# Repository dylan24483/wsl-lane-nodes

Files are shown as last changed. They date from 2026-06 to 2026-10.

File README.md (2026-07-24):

# wsl-lane-nodes

Phase 8 of the Westside Lanes Conqueror replacement project. Each Pi 4 controls one lane pair, replacing the QubicaAMF stack (BCU II + QBK-SIx + T-VISION + VDB-99) with direct GPIO control of the AMF 8270 cabinet I/O. Pi nodes connect to WSL-SRV via WebSocket and feed events into the existing wsl_scoring_engine.

## Status: bench rig fully validated (2026-05-06)

**What runs end-to-end on the bench:**

- [x] Pi GPIO + WebSocket + scoring engine + browser display (night-1 prototype, 2026-05-01)
- [x] AEDIKO 8-channel relay HAT + AL-ZARD DST-1R8P-P opto-input bench rig validated
- [x] Per-pair (lanes 21 + 22): 4 inputs (foul × 2 + 2nd-ball × 2) + 4 outputs (cycle × 2 + power × 2)
- [x] Both control modes proven: pulsed cycle + latched power on/off
- [x] Production safety: SIGTERM handler + `try/finally` on `pulse()` + systemd `ExecStopPost=` cleanup (3 of 4 K-mitigations; hardware watchdog is the 4th)
- [x] Foul-event vs ball-detect semantic separation (BALL_EVENT carries pin_mask + foul flag)
- [x] OpenCV pin-detect pipeline skeleton (synthetic-image self-test passes)
- [x] SQLite state persistence — server restarts don't wipe in-progress games
- [x] WebSocket protocol versioning
- [x] Server portable to WSL-SRV (Windows) or stays on Pi for dev

**Active gates before Phase 8a cutover:**

- [ ] Lane 22 characterization visit — see [docs/lane_visit_checklist.md](docs/lane_visit_checklist.md)
- [ ] T-Camera + USB capture dongle on bench — calibrate `pin_detect.PIN_SPOTS` against real frames
- [ ] Hardware watchdog perfboard build — see [docs/hardware_watchdog_design.md](docs/hardware_watchdog_design.md)

## Layout

| Path | What |
|---|---|
| `lane_node/lane_node.py` | Pi-side daemon — multi-lane GPIO, WebSocket client, signal handlers |
| `lane_node/relay_cleanup.py` | Standalone GPIO cleanup script run by systemd `ExecStopPost=` |
| `lane_node/pin_detect.py` | OpenCV pipeline skeleton + synthetic-image self-test |
| `server/lane_node_server.py` | Server — WebSocket + HTTP display + desk simulator UI + `/api/health` |
| `server/state_store.py` | SQLite persistence helpers + CLI for state inspection |
| `systemd/lane-node.service` | systemd unit for production deployment |
| `prototypes/` | Scaffolding scripts that proved individual pieces during night-1 |
| `wsl_scoring_engine.py` | Copied from wsl-systems — handles bowling logic |
| `docs/lane_visit_checklist.md` | On-site procedure for the lane characterization visit |
| `docs/hardware_watchdog_design.md` | CD4538B + MOSFET watchdog circuit spec for the 4th K-pillar |
| `docs/deploy_server_to_wsl_srv.md` | Step-by-step for moving the server to WSL-SRV |

## Run on the Pi

Two SSH sessions, server in one + lane node in the other:

```bash
# Session 1 — server
cd ~/wsl-lane-nodes && source .venv/bin/activate
WSL_MACHINE_LANES=21,22 \
WSL_SCORING_NODE_TOPOLOGY=pi-lane21-22=21,22 \
WSL_ALLOW_UNAUTHENTICATED_BENCH=1 \
python3 server/lane_node_server.py

# Session 2 — lane node daemon
cd ~/wsl-lane-nodes && source .venv/bin/activate
WSL_LANE_NODE_ID=pi-lane21-22 WSL_DIAG_SOURCE_ID=pi-lane21-22 \
WSL_LANES=21,22 WSL_ALLOW_UNAUTHENTICATED_BENCH=1 \
python3 lane_node/lane_node.py
```

Browser at `http://lane-node-dev.local:8766/` — Open Lane / Close Lane / Reset Pins / Power On/Off / Trigger Ball buttons per lane.

## Run server on WSL-SRV instead of Pi

```bash
# On WSL-SRV (Windows): see docs/deploy_server_to_wsl_srv.md
# On the Pi:
WSL_LANE_SERVER_URL=ws://192.168.4.103:8765 \
WSL_LANE_NODE_ID=pi-lane21-22 WSL_DIAG_SOURCE_ID=pi-lane21-22 \
WSL_LANES=21,22 LANE_NODE_TOKEN=<shared-secret> \
WSL_SCORING_NODE_TOKEN=<unique-pi-secret> python3 lane_node/lane_node.py
# (192.168.4.103 = WSL-SRV since the 2026-06-03 eero re-IP; confirm the live IP —
#  the DHCP reservation is still TODO. The old 192.168.86.36 is dead.)
```

## Health check

```bash
curl http://lane-node-dev.local:8766/api/health
```

Returns server uptime, connected node summary, per-lane state, pending foul flags, state DB path.

## State inspection

```bash
python3 server/state_store.py            # print current saved state
python3 server/state_store.py clear      # wipe saved state
```

## Test pin detection on synthetic frames

```bash
python3 lane_node/pin_detect.py
```

Runs 7 synthetic-image test cases (strike, gutter, head pin only down, 7-10 split, etc.) and reports pass/fail. Validates the pipeline shape; real-camera calibration of `PIN_SPOTS` is a separate step.

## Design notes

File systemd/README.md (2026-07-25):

# Lane-node systemd units — topology & health hand-off

Two units, **mutually exclusive** (`lane-node-controller.service`
`Conflicts=lane-node.service`), one Pi:

| Unit | Track | Role | Health class it emits |
|---|---|---|---|
| `lane-node.service` | A | camera scoring (`lane_node.py`) | `camera_health`, `camera_ref_drift`, `gs_camera_disagree` |
| `lane-node-controller.service` | B | 82-70 controller replacement (`controller_daemon.py`) | `service_restart*`, `pi_thermal`, `pi_disk_low`, `pi_fs_readonly`, `pi_undervoltage`, `uart_drops`, FSM/firmware faults, `fw_identity*` |

Both require the shared per-Pi env (`EnvironmentFile=/etc/wsl-lane-node.env`,
see `wsl-lane-node.env.example`): `WSL_DIAG_SERVER_URL`, `LANE_NODE_TOKEN`,
the distinct `WSL_SCORING_NODE_TOKEN`, `WSL_LANE_NODE_ID`, matching
`WSL_DIAG_SOURCE_ID`, `WSL_BOARD_REVS`, and the exact paired `WSL_LANES`.

## Per-board AUX diagnostics

A two-board service must provision each physical board independently with
`WSL_DIAG_AUX_ROLES_L<lane>`; for example:

```text
WSL_DIAG_AUX_ROLES_L21=aux2=exit_beam,aux3=dist_index,aux10=sensor_24v_ok
WSL_DIAG_AUX_ROLES_L22=aux3=dist_index,aux10=sensor_24v_ok
```

The exit photoeye is one pair-shared sensor, so exactly one board may map
`exit_beam`. The daemon validates this before opening hardware and again when
wiring the pair tracker. `sensor_24v_ok` and `dist_index` remain board-local;
if one supply spans the pair, each board needs its own isolated monitor-contact
pole. Once either board has an explicit map, omission of the mate is a startup
error; a present-but-empty lane variable explicitly leaves that board unmapped.
The legacy unscoped `WSL_DIAG_AUX_ROLES` variable is accepted only when
`WSL_LANES` selects one board; a multi-board service refuses it instead of
silently cloning roles onto an unwired mate.

## R3-2 — controller heartbeat / lease renewal (why a quiet controller stays HEALTHY)

The :8766 server derives each machine lane's board state from a **lease**
(`machine_leases.last_seen`): fresh → HEALTHY/FAULT, stale (> `WSL_MACHINE_LEASE_S`,
default 90 s) → OFFLINE, never-heard → UNKNOWN. Track A refreshes the lease
through the scoring **WS heartbeat**. **Track B sends no scoring WS**, so a
healthy-but-quiet controller used to expire OFFLINE at 90 s (Codex R3-2
wrong-topology bug).

`controller_daemon`'s `PlatformHealth` thread now POSTs
`/api/machine/heartbeat` per board every `WSL_MACHINE_HEARTBEAT_S` (default
20 s — well under the 90 s window), carrying board revision + firmware
build/config hashes + the machine-contract digest + outbox health. The server
touches the lease identically to the WS/ingest path. Requires
`WSL_DIAG_SERVER_URL` set; behind `LANE_NODE_TOKEN` when armed.

## R3-11 — shared health-drop hand-off (why both health classes reach the desk)

Because the two units are mutually exclusive, whichever one is running would
otherwise be the only health class the desk ever sees. The **shared drop file**
`${WSL_DIAG_DIR:-./diag_logs}/health_drop.json` (`lane_node/health_drop.py`,
atomic tmp+`os.replace`) bridges the hand-off:

- Each service writes its **own** last-known health block to the drop file.
- The service that is running (it has transport) also **reads the other
  service's** drop and ships it to the store as an info event flagged with its
  age (`age_s`) — a last-known snapshot, not live.

So on a Track-B (controller) box the desk still sees the camera service's
last-known health, and vice-versa. A read-only filesystem (R3-10) makes the
drop write a counted no-op; the reader simply finds no fresh foreign drop, and
the controller's own platform health still reaches the desk via the network
heartbeat.

## R3-5 — firmware identity ARM gate (controller only)

A rev-D board reports a firmware **identity** line (revision straps, build +
config.h hashes, FI-1 posture). A reboot **invalidates** the cached identity;
the daemon re-requests it. Missing identity (after retries, on a strapped
board) or a mismatch (wrong pcb revision / an FI-1 bench image) **inhibits
ARM**. Bench escape: `WSL_ALLOW_IDENTITY_MISMATCH=1` (loudly logged). rev-B/C
boards and pre-v1.2.2 firmware never report identity and are unaffected.

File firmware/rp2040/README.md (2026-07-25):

# WSL Phase 8b — RP2040 lane-controller firmware

**v1.2.3 — controlled Rev-D-only release artifacts built, but NOT FLASHED; bench/first-article gates remain mandatory before any live-machine use. Full version history and exact release provenance: `CHANGELOG.md` and `release/firmware_manifest.json`.**
*(v1.2.2, 2026-07-21 — Codex round-2 R2-1/R2-13/R2-6 — **NOT flashed**: pad-level OEOVER output lock + `STATUS.OETOPAD` readback on EVERY input-contract pin (the SIO-only check had an override bypass), epoch-aware rail-predicate cause classifier (pre-reboot ring entries are history-only, never fresh diagnosis), the bench-only FI-1 fault-injection build (compile-flag + BOOTSEL-jumper + arm-command gated; separate artifact name; zero code in release), and the identity line: REV_ID strap read (GP20/GP21), Pico unique id, deterministic controlled source/toolchain build ID + config hash, hb `rid` field. All additive; `rp2040_link.py` consumes id/rid.)*
*(v1.2.0, 2026-07-21 — rev-D remediation R3, closes Codex C2 — **NOT yet flashed**: GP16-19 rev-D diagnostic taps get an ENFORCED input-only invariant (choke-point init + register readback each heartbeat + a host direction-invariant test that fails the build if any code path drives them), the INVERTED tap decode (2N7002 stage: raw 0 = observed HIGH, one `tap_read()` inversion point), a 1 ms-timestamped rail-predicate edge ring in noinit RAM that survives reboot (magic + epoch; `TAPDUMP`/`TAPCLR`), and VCC_5V ADC sampling on GP26 folded into the heartbeat. The four taps observe watchdog/ARM/RP2040 predicates only; they do **not** directly observe `RELAY_ENABLE_RAIL`/TP16 and cannot by themselves detect Q14/J14/rail stuck-on or stuck-open behavior. **All additive**: v1.1 line formats + command grammar unchanged, all v1.1 enforcement flags still default OFF, safety-critical paths byte-for-byte logic-identical. Rev-D board only — on rev-B/rev-C these pins are unconnected (an IRQ storm guard keeps floating-pin noise harmless). Binding contract: `docs/phase8_revD_remediation_spec_2026-07-21.md` §R3.)*
*(v1.1.1, 2026-07-06 review fixes (findings 37/56/58): boot `v11` enforcement-posture field; cam-stop grace arms on FIRST trip only; sliding chatter window. v1.1.0, 2026-06-10: cam-stop OVERRUN / SC-TB echo / motion-without-RUN, all default OFF. v0.2.0, 2026-06-10: audit hardening. See CHANGELOG.md.)*

> ⛔ **BENCH-CONFIRM BEFORE ENABLING the v1.1 flags.** `config.h` ships every v1.1 enforcement flag OFF and every per-cam trip edge as `'?'` (UNCONFIRMED). Confirm the per-cam edge→angle polarity on the spare cabinet (`docs/phase8_trackB_controller_cutover_runbook.md` §3.2) FIRST, then set `CAM_*_TRIP` + flip the matching `*_ENABLED` cam-by-cam and generate a new controlled release. Enabling with wrong polarity nuisance-trips the rail (safe direction) or fails to add the intended secondary diagnostic. **Candidate C is decided:** J_SAFE1-2 uses the documented keyed/labeled engineered jumper, while the OEM SC/TB ladder remains the primary hardware collision interlock and must pass the per-lane G3 S/T coil-drop proof. The firmware SC/TB echo remains default-off, unvalidated, and secondary. Never enable it blind or substitute it for the OEM-ladder proof.

One RP2040 (a stock Raspberry Pi Pico module) sits on each Rev-D controller board and is the **fast + safety half** of the lane controller. The Raspberry Pi runs the cycle FSM (`lane_node/cycle_control_8270.py`) and commands relays over I²C/MCP23017; this firmware owns the latency-critical inputs and the hardware rail-permission line. The controlled v1.2.3 bundle supports exactly `["revD"]`; do not flash it on Rev-B or Rev-C hardware.

> ⚠️ **Safety co-processor.** It drives `RP2040_OK` (GP2), a non-bypassable condition in the relay-enable-rail AND chain (spec §4.1). It is **never the only safety device** — the TB/SC collision interlock is the OEM parallel-safe-contact ladder in the S/T coil circuits (Candidate C), while the installed Stop/master-breaker path, NE555 watchdog (which watches the *Pi*), and regenerative motor braking remain hardware-independent of this firmware. Pilot lanes 21/22 have no C.I.S. device or wiring; another pit-entry interlock remains unresolved, and J14.3–4 must stay OPEN/no-arm until the approved isolated Stop/control-power interface and demand proof exist. Read the safety section before editing.

## What it does (v1)

1. **Reads 8 fast inputs** (6 cams + 2 DIELL ball beams), debounces, and **pushes edge events to the Pi over uart0** — the FSM consumes events, it does not poll, so cam timing isn't subject to Pi scheduling latency.
2. **Drives `RP2040_OK` (GP2)** = rail permission. **HIGH only when healthy; LOW on boot, fault, or hang.** Fail-safe by construction (see below).
3. **UART-independent safety backstops:**
   - **Firmware health** — the RP2040 hardware watchdog: if the main loop hangs, the chip resets → GP2 goes Hi-Z → the board's external 100k base-pulldown holds the rail **dead**.
   - **Motion max-run ("cam timeout", spec §4.2)** — if the Pi marks a guarded motor `RUN` and never `STOP`s it within `MAX_MOTION_MS` (8 s, matches the FSM), the firmware **latches a fault and drops RP_OK**.
4. **Heartbeats to the Pi** so a dead/`!ok` RP2040 is detected (the Pi then drops its ARM GPIO → rail drops).

### v1.1 SAFETY supervision (implemented, default OFF — arm per-cam after the §3.2 capture)

These are the cutover **G3 cam-stop rail-drop** backstops. The *code* is present + host-tested; the *enforcement* is gated OFF in `config.h` until the per-cam edge→angle polarity is bench-confirmed (`docs/phase8_trackB_controller_cutover_runbook.md` §3.2). Each only ever `latch_fault()`s (fail-safe: RP_OK → LOW).

1. **Cam-stop OVERRUN** — a stop cam's TRIP edge fires while its guarded motor is marked RUNNING and the Pi fails to `STOP` it within the per-cam grace window → latch `cam_overrun`. Per-cam: `CAM_SA_STOP_ENABLED`/`CAM_SA_TRIP`/`CAM_SA_GRACE_MS` (SA→sweep S), `CAM_TA1_*` (TA1→table T). **The Pi-independent, per-edge stop the post-cutover machine relies on** (runbook §0: cam-stops are SOLELY the RP2040's job once the Omniboard is unplugged).
2. **SC/TB collision-interlock echo** — both firmware inputs asserted at once while a motion motor runs → latch `interlock_collision`. `INTERLOCK_ECHO_ENABLED`. This default-off path is an unvalidated secondary diagnostic. The **primary** guard is Candidate C’s OEM ladder, proven per lane by forcing both levers BACK while the board commands S and T and verifying both coils remain dead.
3. **Motion-without-RUN** — a stop-cam TRIP edge while NO motion motor is marked RUNNING = the machine turning uncommanded (Pi wedged / external start / welded relay) → latch `motion_no_run`. `MOTION_NO_RUN_ENABLED`. The one check that works even if the Pi is fully wedged.

## Authoritative pin map

Source of truth: `scripts/generate_kicad_netlist_revD.py` → `block_rp2040()` and `kicad/wsl-phase8b-revD.net`. Re-verify against both if the board changes. **Do not** use the older `docs/phase8_channel_allocation.md` §2 GPIO column — it predates the live board (it had the fast inputs on GP0–GP7; Rev-D uses GP6–GP13).

| GPIO | Pico pin | Signal | Dir | Net | Notes |
|---|---|---|---|---|---|
| GP0 | 1 | UART0 TX → Pi RX | out | `PI_UART_RX` | protocol transport |
| GP1 | 2 | UART0 RX ← Pi TX | in | `PI_UART_TX` | protocol transport |
| GP2 | 4 | `RP2040_OK` | out | `RP2040_OK` | HIGH=permit, LOW=drop rail; fail-safe-low |
| GP6 | 9 | SA (sweep cam) | in | `FAST_SA` | active-low opto; 270 run-through / 360 zero |
| GP7 | 10 | SB (sweep cam) | in | `FAST_SB` | 66 guard / 186 table-spot init |
| GP8 | 11 | SC (sweep interlock cam) | in | `FAST_SC` | sweep-under-table 86–243 |
| GP9 | 12 | TA1 (table cam) | in | `FAST_TA1` | 355 zero / 185 delay-reset |
| GP10 | 14 | TA2 (table cam) | in | `FAST_TA2` | 260 run-through / pin-latch / ball-strike decision |
| GP11 | 15 | TB (table interlock cam) | in | `FAST_TB` | table-sweep interference 105–255 |
| GP12 | 16 | DIELL-L (ball) | in | `FAST_DIELL_L` | active-low opto; cushion SS trigger |
| GP13 | 17 | DIELL-R (ball) | in | `FAST_DIELL_R` | active-low opto |
| GP16 | 21 | tap: NE555 out (v1.2, **rev-D only**) | in (ENFORCED) | `TAP_NE555_OUT` | 2N7002 stage **INVERTS**: raw 0 = observed HIGH |
| GP17 | 22 | tap: watchdog kick (v1.2, rev-D) | in (ENFORCED) | `TAP_WDOG_KICK` | inverted |
| GP18 | 24 | tap: ARM permit (v1.2, rev-D) | in (ENFORCED) | `TAP_ARM_PERMIT` | inverted |
| GP19 | 25 | tap: RP2040_OK echo (v1.2, rev-D) | in (ENFORCED) | `TAP_RP2040_OK` | inverted; cross-checked vs our own GP2 |
| GP20 | 26 | REV_ID0 strap (v1.2.2, rev-D) | in (ENFORCED) | `REV_ID0` | 10k→3V3 on rev-D; read once at boot, pull-phase floating detect |
| GP21 | 27 | REV_ID1 strap (v1.2.2, rev-D) | in (ENFORCED) | `REV_ID1` | 10k→GND on rev-D; `REV_ID[1:0]=GP21<<1\|GP20`, rev-D=0b01 |
| GP26 | 31 | VCC_5V sense (v1.2, rev-D) | ADC0 | `ADC_VCC5_SENSE` | VCC_5V/2 via 10k/10k divider |

All fast inputs are **active-low** at the Pico (machine contact closed → GPIO LOW). Rev-D uses an on-board **47k** pull-up to 3V3; firmware explicitly disables the RP2040 internal pulls so their ~50–80k tolerance cannot sit in parallel and reduce the qualified optocoupler margin. A missing external pull-up is a board fault, not something firmware masks. The v1.2 diagnostic-tap pins are separate: they remain input-only with pulls OFF and use their own on-board **10k `Rtapd_*` drain pull-ups**. `tap_assert_input_only()` reads back the OE/function registers every heartbeat and latches a fail-safe `tap_dir` fault on drift; the host test fails the build if any code path ever drives them. **v1.2.2 (R2-1):** the invariant additionally forces + verifies the pad-level `CTRL.OEOVER=DISABLE` override and the live `STATUS.OETOPAD` bit on EVERY input-contract pin (taps, GP26, fast inputs, REV_ID) — the SIO-only readback had an OEOVER bypass; drift latches `pad_oe`.

## Build

Needs the [Raspberry Pi Pico SDK](https://github.com/raspberrypi/pico-sdk) + `arm-none-eabi-gcc` + CMake.

```powershell
# Controlled release path: host tests + clean release/FI-1 builds + manifest + verification
powershell -ExecutionPolicy Bypass -File .\release.ps1

# Re-verify an existing bundle before it is copied or flashed (no ARM toolchain needed)
powershell -ExecutionPolicy Bypass -File .\release.ps1 -VerifyOnly
```

`release.ps1` fixes `Release`, `PICO_BOARD=pico`, `DEBUG_USB=OFF`, refuses ambient
compiler/linker flags and a dirty Pico SDK, builds the release and FI-1 variants, and
writes `release/firmware_manifest.json`. The manifest binds both UF2 SHA-256 values to:

- the exact on-wire `id.build`, `id.cfg`, and `id.fi1`;
- full config/source-input SHA-256 values and the variant compile options;
- the clean Pico SDK commit, ARM compiler/CMake/Ninja versions, and CMake-cache hashes.
- an exact `supported_board_revisions: ["revD"]` deployment policy.
- an authoritative exact release tuple:
  `qualified_releases: ["revD|rel-0c746b5747143b8011b01d43|05d808411db4bb0d"]`.

The two exact manifest-named UF2s are committed as ordinary binary Git blobs:

- production `release/wsl_phase8b_rp2040.uf2` — SHA-256
  `d5570efd19c374d9ca4532b78ef36577ae93b88160b5c1775e92d1ef88c40aae`;
- bench-only `release/wsl_phase8b_rp2040_FI1.uf2` — SHA-256
  `7c1daabad0a102f55fa61d617d3b4f0722705770f109e2d941b5356b3378ae6c`.

`.gitattributes` pins every byte-hashed controlled source input to LF, so
`core.autocrlf` cannot change a clean-clone identity. The UF2 rules explicitly
disable text conversion, diff/merge drivers, and inherited LFS filters.

`id.build` is derived from the explicit firmware source/recipe allowlist,
image-affecting options, exact clean Pico SDK commit, and C compiler ID/version. A
different SDK/compiler therefore cannot announce the allowlisted identity. Application
repository Git status, timestamps, and unrelated dirty files are not inputs. `id.cfg` is
exactly the first 16 hex characters of `sha256(config.h)`. The manifest's
`qualified_releases` tuple is the authoritative ARM policy and is emitted as
`WSL_RP2040_QUALIFIED_RELEASES`; `supported_board_revisions` is emitted as
`WSL_RP2040_SUPPORTED_BOARD_REVISIONS`. Both must be provisioned. The independent
build/config lists remain provenance records only; they must never authorize their
Cartesian product. The FI-1 identity is deliberately excluded from every production policy.

`build.ps1` and direct CMake remain useful for developer/debug builds, but their output is
not a release artifact until the two-image manifest path above completes. **v1.2.3
re-verified 2026-07-23:** both images built successfully and their embedded identities and
hashes passed the independent manifest verifier. This is build evidence only, not flash or
bench evidence.

## Host logic test (no hardware)

The pure logic (TX ring, debounce/edges, ball lockout, UART protocol, the RP_OK safety supervisor) has a host unit test that mocks the Pico SDK — build + run it with any host C compiler:

```bash
# from firmware/rp2040/  (gcc or a MinGW clang; plain clang on Windows needs the Windows SDK for libc headers)

# (a) default build — v1.1 enforcement flags OFF (what ships); also pins the off-by-default inertness
gcc -std=c11 -Wall -Wextra -Werror -I test -I test/stubs test/test_main.c -o test/test_main.exe
./test/test_main.exe        # exit 0 = all checks pass

# (b) v1.1 SAFETY paths — SAME firmware, enforcement flags forced ON with test polarities ('f')
gcc -std=c11 -Wall -Wextra -Werror -I test -I test/stubs \
  -DCAM_SA_STOP_ENABLED=1 -DCAM_SA_TRIP="'f'" -DCAM_SA_GRACE_MS=150u \
  -DCAM_TA1_STOP_ENABLED=1 -DCAM_TA1_TRIP="'f'" -DCAM_TA1_GRACE_MS=150u \
  -DINTERLOCK_ECHO_ENABLED=1 -DMOTION_NO_RUN_ENABLED=1 \
  test/test_v11.c -o test/test_v11.exe
./test/test_v11.exe         # exit 0 = all checks pass

# (c) v1.2 tap/ring/ADC + THE C2 DIRECTION-INVARIANT GATE (rev-D remediation)
#     v1.2.2 adds: R2-1 OEOVER mutation gate, R2-13 epoch classifier, R2-6 REV_ID/identity
gcc -std=c11 -Wall -Wextra -Werror -I test -I test/stubs test/test_v12.c -o test/test_v12.exe
./test/test_v12.exe         # exit 0 = all checks pass

# (d) FI-1 bench build gates (v1.2.2 + v1.2.3): jumper refusal, arm-gate, drive/release,
#     banner identity, AND the v1.2.3 dead-man release paths (arm/drive timeout, UART loss, KA)
gcc -std=c11 -Wall -Wextra -Werror -I test -I test/stubs -DFI1_ENABLED=1 \
  test/test_fi1.c -o test/test_fi1.exe
./test/test_fi1.exe         # exit 0 = all checks pass
```

Last run: **64/64** (`test_main`) + **32/32** (`test_v11`) + **140/140** (`test_v12`) + **44/44** (`test_fi1`) checks passed (2026-07-23, gcc 16.1.0), all clean under `-Wall -Wextra -Werror` + the `printf`-format attribute (so the event format strings are compiler-verified too). The binaries share `test/mock_impl.h` (one mock-SDK implementation) so they can never drift. Sections F–I of `test_main` pin the v0.2.0 hardened semantics (UART fuzz/overrun-discard, duplicate-RUN, uint32 ms-wrap boot-settle latch, chatter guard + TX headroom, hb `in`/`run` masks); Section J pins that the v1.1 checks are **inert when the flags are OFF** (a default build = v0.2.0 enforcement); `test_v11.c` pins that each v1.1 fault path fires fail-safe when enabled (overrun latch + timely-STOP-cancels + per-motor disarm, SC∧TB echo, motion-without-RUN, and the non-trip-edge-is-inert guard). `test_v12.c` is the **C2 gate**: the mock SDK records every output-direction/write call per pin and the test FAILS if GP16-19/GP26 ever appear in one across init + operation + every fault path; it also requires all fast-input internal pulls OFF so Rev-D's qualified external 47k remains authoritative, tampers the mock OE register to prove `tap_assert_input_only()` trips, and covers the inverted decode, ring capture/wrap, reboot-persistence + epoch semantics, power-loss zeroing, TAPDUMP/TAPCLR + cause classification, ADC window, IRQ storm guard, and the RPOK cross-check (warn-only by default). **v1.2.3 (round-3)** adds `test_v12.c` section T (per-boot `bn` nonce: non-zero, differs across boots, id/hb-consistent, 0-reservation guard) and section U (the **R3-6 CLEAR pad-revalidation**: a violated input-only pad makes CLEAR a strict no-op — nak, fault stays latched, RP_OK stays low — while the fail-safe motor-stop half still runs), and `test_fi1.c` section E (the **FI-1 dead-man** release paths: arm timeout, drive timeout, UART loss, and the continuous `FI1 KA` token, plus a positive test that the 1 Hz bench KA cadence holds an injection with no false release).

> ⚠️ **Bench-only gates (the host test CANNOT prove these):** watchdog timing (the 250 ms WDT vs real loop latency — the mock watchdog is a no-op), boot ordering (GP2 LOW before init), GPIO drive polarity/levels on real silicon, UART electricals/baud, and the DEBUG_USB stdio path. These are §12.9 bench bring-up items — a green host test is necessary, not sufficient.

## Flash

1. Read the physical PCB marking and Rev-ID straps. Stop unless the board is Rev-D.
2. Run `release.ps1 -VerifyOnly`. Do not flash if any source digest, UF2 SHA-256,
   embedded identity check, or exact `supported_board_revisions: ["revD"]` policy fails.
   Never use this bundle on Rev-B/Rev-C.
3. Record the release-manifest SHA-256, release-image SHA-256,
   `supported_board_revisions`, and the exact `qualified_releases[0]` tuple from
   `release/firmware_manifest.json`. Provision that tuple as
   `WSL_RP2040_QUALIFIED_RELEASES` and provision the board list as
   `WSL_RP2040_SUPPORTED_BOARD_REVISIONS`; never reconstruct authorization by
   mixing independent build/config allowlists.
4. **USB BOOTSEL (preferred):** hold BOOTSEL while connecting USB; when `RPI-RP2`
   mounts, drag-drop **`release/wsl_phase8b_rp2040.uf2`**. Never substitute the
   `_FI1.uf2` bench image.
5. **SWD fallback:** `picotool load -x release/wsl_phase8b_rp2040.uf2`, or OpenOCD via
   the board's SWD test points.
6. After boot, request `ID` and require `pcb:"revD"`, `fw`, `build`, `cfg`, and
   `fi1:0` to match the verified manifest exactly. A filename or version banner alone
   is not proof of the image. The current v1.2.3 image still is not cutover-ready
   because its cam-stop enforcement flags are OFF.

## UART protocol (115200 8N1, newline-delimited)

### RP2040 → Pi (events)
```
{"ev":"boot","fw":"phase8b-rp2040 v1.2.0","wdt_reset":0,"rp_ok":0,"maxrun_ms":8000,"dbg":0,"v11":{"sa":"off","ta1":"off","echo":0,"nrun":0},"tap":{"ep":1,"pre":0,"n":0}}
{"ev":"cam","id":"SA","e":"f","t":12345}        # e: f=asserted(fall), r=released(rise)
{"ev":"ball","src":"L","t":12350}               # one event per ball (lockout-deduped)
{"ev":"rp_ok","v":1,"t":12360}                  # rail permission changed
{"ev":"flt","code":"motion_timeout","m":"S","t":20000}
{"ev":"flt","code":"chatter","m":"SA","t":20000}   # input over the per-window edge budget
{"ev":"flt","code":"cam_overrun","m":"SA","t":20000}          # v1.1, when enabled: stop cam tripped, motor not STOPped in grace
{"ev":"flt","code":"interlock_collision","m":"SCTB","t":20000} # v1.1, when enabled: SC+TB both asserted while a motor runs
{"ev":"flt","code":"motion_no_run","m":"SA","t":20000}        # v1.1, when enabled: stop-cam trip with no motor commanded
{"ev":"flt","code":"tap_dir","m":"KICK","t":20000}            # v1.2: tap pin OE/function register drift (enforced invariant)
{"ev":"flt","code":"pad_oe","m":"555","t":20000}              # v1.2.2: CTRL.OEOVER/STATUS.OETOPAD drift on an input-contract pin
{"ev":"hb","ok":1,"flt":"","up":12500,"drp":0,"in":0,"run":0,"tap":0,"rd":0,"ep":1,"v5":4810,"v5n":4650,"v5x":4885,"rid":1}
{"ev":"id","fw":"phase8b-rp2040 v1.2.3","pcb":"revD","rid":1,"uid":"E66038B713952A31","build":"rel-<24 hex>","cfg":"<16 hex>","fi1":0,"t":300}  # exact values come from release/firmware_manifest.json
{"ev":"ack","cmd":"CLEAR","t":21000}
{"ev":"tapdump","n":17,"ep":2,"br":2,"mut":0,"cause":"kick_starvation","t":30000}  # v1.2: TAPDUMP header
{"ev":"tape","i":0,"t":29450,"p":1,"l":0,"ep":1}   # v1.2: one ring entry (p: 0=555,1=KICK,2=ARM,3=RPOK; l=post-inversion level AFTER the edge)
{"ev":"tapdump_end","n":17}                        # v1.2: dump complete
{"ev":"tapwarn","code":"rpok_mism","t":30500}      # v1.2: GP19 tap disagrees with our GP2 drive (warn-only by default)
```

v1.1 fault codes (`cam_overrun`/`interlock_collision`/`motion_no_run`) appear ONLY on a build with the matching `config.h` flag enabled; a stock (default) firmware never emits them. They are ordinary `flt` events — the Pi side already treats any `flt` as not-healthy (`rp2040_link._handle`), so **no Pi-side change is required to react to them**. A `CLEAR` (issued from a known-safe state) clears them like any other latched fault.

Boot fields (v0.2.0): `maxrun_ms` = the firmware's compile-time max-run backstop — **the Pi should refuse to arm if its `MAX_MOTION_S` exceeds it** (the two are independently-maintained constants); `dbg` = 1 marks a DEBUG_USB build so a debug image at the lane is visible.

Boot fields (v1.1.1): `v11` = the v1.1 enforcement posture, because `fw` is the SAME string for an armed and a stock build (review finding 37). `sa`/`ta1` = `"off"` (per-cam enable 0) or the configured trip edge (`"f"`/`"r"`, `"?"` = enabled-but-unconfirmed, which can never trip); `echo`/`nrun` = `INTERLOCK_ECHO_ENABLED`/`MOTION_NO_RUN_ENABLED`. `rp2040_link` logs the posture at every boot (WARNING when armed) and exposes it via `v11_posture()` — **verify the expected posture at cutover before crediting the G3 cam-stop backstop.** Additive field: older Pi-side parsers ignore it.

Heartbeat masks (v0.2.0): `in` = debounced input levels, bit *i* = `inputs[i]` asserted (SA,SB,SC,TA1,TA2,TB,DIELL_L,DIELL_R = bits 0–7); `run` = motors marked running, bit *i* = `motors[i]` (S,T,SP,M2,M1,BE,M = bits 0–6). The Pi should **resync its SC/TB interlock echo from `in` on every hb** instead of trusting edge history (a single dropped `cam` line otherwise latches a danger flag forever), and treat an `up` regression as an RP2040 reboot.

UART robustness (v0.2.0): an RX line longer than 63 chars is discarded **whole** (tail swallowed to the next newline — garbled noise can never re-parse as `STOP`/`CLEAR`); a duplicate `RUN <m>` does **not** reset the max-run timer; cam/ball TX lines only enqueue while `TXR_HEADROOM` (128 B) stays free so a flood can't starve `hb`/`flt`; an input exceeding its debounced-edge budget (`CHATTER_MAX_CAM`=8, `CHATTER_MAX_DIELL`=30) inside **any** 100 ms span latches a fail-safe `chatter` fault naming the input (v1.1.1: true sliding window — the old tumbling window needed up to 2× the budget for a burst straddling a window boundary, review finding 58).

Run-state reconciliation (v1.1.1, Pi-side): `RUN`/`STOP` still have no ACK/CRC, but `rp2040_link` now compares the hb `run` mask against the state it last commanded every heartbeat and re-sends the command on mismatch (bounded, 3/episode; safe because duplicate `RUN` doesn't reset the timer). A desync from one corrupted line therefore heals within ~250 ms instead of guaranteeing a spurious `motion_timeout` rail-drop (lost `STOP`) or a silently absent max-run backstop (lost `RUN`) — review finding 38. A persisting mismatch stays visible via `run_mismatch()`.

### Pi → RP2040 (commands)
```
RUN <m>      # mark motor running: m ∈ {S,T,SP,M2,M1,BE,M}  (BE/M not max-run-guarded)
STOP <m>     # mark motor stopped;  STOP *  = all
CLEAR        # clear a latched fault (Pi issues ONLY from a known-safe zero/ready state)
PING         # → immediate heartbeat
TAPDUMP      # v1.2: emit the tapdump header + drip the full edge ring (tape lines) + end marker
TAPCLR       # v1.2: empty the edge ring (the ONLY thing that does — reboot never clears it) → ack
ID           # v1.2.2: re-emit the identity line
# FI1 ARM / FI1 DRIVE <0-3> / FI1 RELEASE — BENCH-ONLY FI-1 build (-DFI1_BUILD=ON): the grammar
# does not exist in a release image; the FI-1 image refuses to run without its BOOTSEL jumper.
```

**FI-1 boot procedure (round-3 doc fix — the jumper gate vs the RP2040 bootrom):** BOOTSEL
held at power-on is intercepted by the ROM ITSELF — the chip enters the RPI-RP2 USB
bootloader and the FI-1 image never runs. A plain power cycle with the jumper fitted can
therefore NEVER satisfy the gate; that is bootrom behavior, not a defect. The two working
sequences are:

1. **Button (single session):** hold BOOTSEL → plug USB (RPI-RP2 appears) → drag
   `wsl_phase8b_rp2040_FI1.uf2` → **keep holding through the automatic reboot into the
   image** → release only after the FI-1 banner (`"fi1":1`) prints on the UART.
2. **Jumper + picotool (repeatable):** fit a jumper across the BOOTSEL pads → plug USB
   (lands in RPI-RP2 every power-up — expected) → `picotool reboot` (or re-drag the
   .uf2); the image boots with the jumper present and the gate passes. Remove the jumper
   only after the banner.

Booting the FI-1 image without the jumper (e.g. picotool reboot with nothing fitted) is
the PERMANENT `fi1_nojumper` refusal — that is the gate working. Do NOT rebuild with the
check stubbed to "get past" it; use sequence 1 or 2.

v1.2 tap fields: hb `tap` = post-inversion observed-net levels (bit 0..3 = 555, KICK, ARM, RPOK), `rd` = ring depth, `ep` = ring epoch, `v5`/`v5n`/`v5x` = VCC_5V latest/min/max mV over the hb window. Boot `tap.ep` = epoch, `tap.pre` = 1 if a valid pre-reboot ring was ADOPTED (0 = zeroed: power loss/first boot), `tap.n` = preserved entries. `tapdump.br` = boot reason (0 cold, 1 soft reboot, 2 watchdog), `mut` = storm-guard-muted tap mask, `cause` = ADVISORY drop classification (`kick_starvation` / `arm_drop` / `self_health` / `555_drop` / `none`) — the Pi always gets the raw ring + per-entry epochs to judge for itself. All fields additive; `rp2040_link.py` verified to ignore them and the new event kinds cleanly (no Pi-side change required).

### Pi-side integration — implemented in `lane_node/rp2040_link.py`
`RP2040Link` + `dispatch_cam()` implement this contract (host test **29/29**, 2026-06-03), and `controller_io.MachineIO`/`RecordingIO` now accept `rp2040=link` for the SC/TB interlock echo + RUN/STOP (resolving the old `interlock_ok()` TODO). The per-board reader does all of:

- **Cam events → FSM** (the FSM's state self-selects which call fires, so call both variants):

  | cam event `id` | FSM call(s) |
  |---|---|
  | `SA` | `c.cam_SA_runthrough(); c.cam_SA_zero()` |
  | `SB` | `c.cam_SB_guard()` |
  | `TA1` | `c.cam_TA1_delayreset(); c.cam_TA1_zero()` |
  | `TA2` | `c.cam_TA2_runthrough()` |
  | `SC` / `TB` | update the interlock echo → feed `interlock_ok()` |
  | `ball` | `c.on_ball()` |

  Act on the **trip edge** (which of `f`/`r` is the angular trip is a bench-confirm item — cams are normally-closed and the opto inverts; default assumes `f` = trip).
- **Send RUN/STOP** alongside the relay commands — e.g. in `MachineIO._set_out`, when `S` toggles, also send `RUN S` / `STOP S`. Send `CLEAR` at `_finish_cycle`/READY.
- **Consume `hb`/`rp_ok`** — if heartbeats stop (>~1 s) or `ok:0`, call `io.arm(False)` to drop the rail; surface faults to the FSM/desk.
- **SC/TB echo** — track asserted state from cam events → replace the `interlock_ok()` TODO. **v0.2.0 TODO(pi-side):** resync the SC/TB flags from the hb `in` mask every heartbeat (self-healing vs dropped lines), verify `boot.maxrun_ms >= MAX_MOTION_S*1000` before arming, and treat an `up` regression as an RP2040 reboot (same safety-trip path as a `boot` event).

## Safety model — why RP_OK is fail-safe

- **Pre-init / unpowered / reset:** GP2 is Hi-Z → the board's 100k base-pulldown holds the NPN off → RAIL_GATE stays pulled up → PMOS off → **rail dead**. `main()` drives GP2 LOW first thing, then HIGH only after `BOOT_SETTLE_MS` and only while no fault.
- **Loop hang:** RP2040 hardware watchdog (`WDT_TIMEOUT_MS`) resets the chip → back to Hi-Z → rail dead → auto-recovers on reboot (a `boot` event with `wdt_reset:1` tells the Pi it happened).
- **Telemetry never blocks safety:** UART TX is a non-blocking ring buffer; if the Pi isn't draining, whole lines are dropped (counted in `hb.drp`) — the RP_OK drive and watchdog kick still run every loop pass.
- **Dead UART can't cause unsafe motion:** no `RUN` messages → nothing marked running → no false permit; and the Pi's own motion-timeout FAULT drops ARM. A UART death *mid-run* is caught by the RP2040 max-run timer.

## Bench bring-up (do this on a LOCKED-OUT / off machine — spec §12.9)

1. **Power + boot:** flash, power the board logic only (rail externally safe). Watch USB/UART: a `boot` line, then `hb` at ~4 Hz with `ok:1` after ~200 ms. Confirm GP2 reads HIGH (rail-permit) on a meter/test-pad once healthy.
2. **Inputs:** hand-actuate each cam / break each DIELL beam → confirm the matching `cam`/`ball` event (correct `id`). This also captures the per-cam edge polarity for the v1.1 hook + the cutover field sheet.
3. **Watchdog drop:** pause the loop (or pull power to just the Pico) → GP2 → LOW → rail drops. Confirm a `boot` with `wdt_reset:1` if you force a hang.
4. **Motion timeout:** send `RUN S`, wait >8 s without `STOP S` → expect `{"ev":"flt","code":"motion_timeout","m":"S"}` and GP2 → LOW. `CLEAR` → GP2 back HIGH.
5. **v1.1 cam-stop arming (per cam, AFTER step 2 captured polarity):** for each stop cam, set `CAM_<cam>_TRIP` to the confirmed trip edge + `CAM_<cam>_STOP_ENABLED=1` in `config.h`, rebuild + re-flash, then the **G3 cam-stop sub-test:** send `RUN S`, hand-rotate so SA trips, do NOT send `STOP S` → within `CAM_SA_GRACE_MS` expect `{"ev":"flt","code":"cam_overrun","m":"SA"}` + GP2 → LOW (repeat for `TA1`/`T`). Then re-run step 4-style with a *timely* `STOP S` inside the grace window and confirm NO fault (the normal stop). Optionally enable `INTERLOCK_ECHO_ENABLED` once the SC/TB windows are confirmed (`SC`+`TB` asserted while a motor runs → `interlock_collision`) and `MOTION_NO_RUN_ENABLED` (trip a stop cam with nothing commanded → `motion_no_run`). **Do not enable any v1.1 flag before its polarity is confirmed in step 2.**
6. **Then** integrate with the rail/relay section per spec §12.9 (each relay with a dummy load, arm drop, interlock drop) before any machine harness.

## Files
- `config.h` — pin map (authoritative, cites the netlist), timing, protocol tokens, **v1.1 per-cam stop descriptors + enforcement flags (all default OFF/UNCONFIRMED)**, **v1.2 tap/ring/ADC constants** (binding contract: remediation spec §R3), **v1.2.2 REV_ID straps + FI1 gate + identity fallbacks**.
- `main.c` — inputs/debounce, UART protocol + TX ring, safety supervisor (incl. the v1.1 cam-stop / SC-TB-echo / motion-without-RUN paths), **v1.2 tap section** (choke-point init, enforced direction invariant, edge ring + persistence, TAPDUMP/TAPCLR, ADC, storm guard), **v1.2.2** pad-OE lock (R2-1), epoch-aware classifier (R2-13), REV_ID/identity (R2-6), FI-1 hooks, main loop.
- `fi1_bootsel.c` — FI-1 bench build ONLY: BOOTSEL physical-jumper gate (never linked into release).
- `gen_build_id.cmake` / `release_provenance.py` — deterministic controlled-input
  `build_id.h` generation plus UF2/manifest verification.
- `release_manifest_policy.py` — stamps/verifies the exact Rev-D deployment scope
  without changing the identity-bearing firmware source set.
- `release.ps1` / `release/firmware_manifest.json` — the only controlled two-image
  release path and its machine-readable artifact/source/toolchain/board-policy record.
- `CHANGELOG.md` — full version history (v0.1.0 → v1.2.3) with per-version flash status.
- `test/mock_pico.h` / `test/mock_impl.h` — host-test mock SDK surface (declarations / one shared implementation; v1.2 adds per-pin direction/write recording + IRQ/ADC/sync mocks; v1.2.2 adds the IO_BANK0 OEOVER/OETOPAD register file with real-SDK whole-CTRL-rewrite semantics, pulls/floating, unique-id).
- `test/test_main.c` — default host test (flags OFF) + Section J off-by-default inertness.
- `test/test_v11.c` — v1.1 host test (flags forced ON via `-D`): each new fault path fires fail-safe.
- `test/test_v12.c` — **v1.2 host test = the C2 direction-invariant gate** + tap decode/ring/persistence/dump/ADC/storm-guard/cross-check coverage; **v1.2.2 sections M-Q**: the R2-1 OEOVER mutation gate, R2-13 stale-edge exclusion, REV_ID/identity, FI-1-absent-in-release.
- `test/test_fi1.c` — **FI-1 bench-build host test** (`-DFI1_ENABLED=1`): jumper refusal permanence, arm-gate, drive/release restore, banner identity.
- `CMakeLists.txt`, `pico_sdk_import.cmake` — Pico SDK build (v1.2 links `hardware_adc`; v1.2.2 links `pico_unique_id`, generates `build_id.h` every build, and offers `-DFI1_BUILD=ON` → separately-named bench artifact).

## Status / next
- v1 written + **verified 2026-06-03**; **clean-room rebuild re-verified 2026-06-04** (full from-scratch ARM cross-build 88/88 + host test 24/24, both **0-warning** under `-Wall -Wextra`; `.uf2` = 40 KB, 24 KB flash / 2.6 KB RAM): host logic test 24/24 + clean ARM cross-build → `.uf2`; Pi-side reader/daemon done and Codex-audited (fixes applied).
- **v0.2.0 audit hardening 2026-06-10** (fable-audit P3 items): host test **55/55** + clean ARM cross-build re-verified (`.uf2` = 41.5 KB), both 0-warning. **NOT yet flashed/bench-run** — needs: re-flash, hb `in`/`run` masks observed on the wire, chatter fault provoked with a function generator or relay buzzer, and the Pi-side resync/maxrun-check TODOs in `rp2040_link.py` (see Pi-side integration above).
- **v1.1.0 SAFETY supervision written 2026-06-10** (fable-audit novel idea #13): cam-stop OVERRUN + SC/TB collision echo + motion-without-RUN, all default OFF behind per-cam config flags. Host tests **61/61** (`test_main`, incl. off-by-default inertness) + **28/28** (`test_v11`, flags forced on), both 0-warning under `-Wall -Wextra -Werror`; clean ARM cross-build re-verified (`.uf2` = 43.5 KB). **NOT yet flashed/bench-run; all v1.1 flags ship OFF** — so on-the-wire behavior is still exactly v0.2.0 until a board is armed cam-by-cam.
- **v1.1.1 review fixes 2026-07-06** (phase8 fable review findings 37/56/58 + Pi-side 38): boot `v11` posture field, arm-once cam-stop grace, sliding chatter window; `rp2040_link.py` gains hb `run`-mask reconciliation (bounded re-sends + `run_mismatch()`) and `v11_posture()`. Host tests **64/64** (`test_main`) + **32/32** (`test_v11`), Pi-side self-tests green. **NOT yet flashed — owner review + re-flash pending; all v1.1 flags still ship OFF.**
- **v1.2.0 rev-D tap telemetry 2026-07-21** (remediation spec R3 — closes Codex C2): enforced input-only invariant on GP16-19 (choke-point init + register readback + host direction-invariant test), inverted tap decode, noinit rail-predicate edge ring with reboot persistence + `TAPDUMP`/`TAPCLR`, VCC_5V ADC in the heartbeat. These predicate transitions support advisory cause inference only; no tap directly measures `RELAY_ENABLE_RAIL`/TP16. Host tests **64/64 + 32/32 + 71/71** (new `test_v12`), all `-Werror`-clean; ARM cross-build verified (`.uf2` = 56 KB, 32.7 KB flash / 5.4 KB RAM; `.map` confirms `tap_ring` in `.uninitialized_data`, outside crt0 zero-fill). `rp2040_link.py` verified compatible unmodified (38/38 + v1.2-line feed check). **NOT yet flashed.** Bench gates: real-silicon reboot persistence, ADC-vs-DMM, `TAP_KICK_STARVE_MS` vs measured NE555 window (v1.2.1: 2000 ms, derived from the real 1 Hz Pi kick cadence — v1.2.0's 300 ms was sized against a nonexistent "~250 ms kick" and misclassified live-train 555 drops), and the R1.9 fault-injection procedure.
- **v1.2.2 Codex round-2 slice 2026-07-21** (R2-1 + R2-13 + R2-6): pad-level OEOVER lock + `OETOPAD` readback on every input-contract pin (the R2-1 override bypass — with the mandated OEOVER *mutation* test), epoch-aware rail-predicate cause classifier (pre-reboot edges history-only), the FI-1 bench fault-injection build (compile-flag + BOOTSEL-jumper + arm-gated; **separate artifact name `wsl_phase8b_rp2040_FI1.uf2`; zero FI-1 code in release** — the R1.9 target that was previously "not yet written"), and the identity line (REV_ID strap read GP20/21 with floating detection, Pico unique id, deterministic controlled-source build ID + config hash via `build_id.h`, hb `rid`). Host tests **64/64 + 32/32 + 111/111 + 28/28** (`test_fi1` new), `-Werror`-clean; ARM cross-builds verified: release `.uf2` = 60.5 KB (real build identity embedded, `tap_ring` still noinit) + FI-1 bench 63 KB. Pi-side `rp2040_link.py` consumes `id`/`rid` (self-test 45/45; `tests/test_fw_identity_line.py`). **NOT flashed.** New bench gates: BOOTSEL-read on silicon, REV_ID strap levels, FA-7 OEOVER/pad behavior on real pads.
- ⚠️ **NOT cutover-ready.** "Done" = host-logic + build only. The cutover runbook's **G3 cam-stop rail-drop gate** now has its firmware *logic*, but the **enforcement is gated OFF** pending the per-cam edge→angle polarity field capture (runbook §3.2). A stock build still provides only health + the motion **max-run backstop**.
- Next: first-article bring-up steps 1–4 (above), wire the Pi-side reader (contract above), then **bench step 5**: capture cam polarity (§3.2), set `CAM_*_TRIP` + flip `*_ENABLED` cam-by-cam, generate a **new controlled Rev-D-only bundle** through `release.ps1`, record its manifest/UF2 hashes, and run the G3 cam-stop drop sub-test per cam.

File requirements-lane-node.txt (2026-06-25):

# WSL Phase 8 lane-node -- minimal runtime deps for a fresh Raspberry Pi provision.
#
# Pinned to the versions on the known-good Pi image. The repo-root requirements.txt
# is the FULL OS pip-freeze (300+ pkgs incl. system packages); THIS file is the
# focused set the lane-node actually imports, for a clean venv install:
#
#   python3 -m venv .venv
#   .venv/bin/pip install -r requirements-lane-node.txt
#
# NOTE: gpiozero needs a GPIO backend. On Pi 5 / recent Pi OS that's lgpio, with
# the rpi-lgpio shim providing the legacy RPi.GPIO API. Both are pinned below.
# No OpenCV: Track-A capture uses PyAV (av) + numpy, deliberately (HANDOFF).
# No Flask: the Pi node is a WebSocket CLIENT; the dashboard/server runs on WSL-SRV.

# --- GPIO / hardware backend (both tracks) ---
gpiozero==2.0.1
lgpio==0.2.2.0
rpi-lgpio==0.6

# --- Track B controller: 3x MCP23017 over I2C + the RP2040 over UART ---
smbus2==0.4.3
pyserial==3.5

# --- Track A camera scoring: USB capture dongle (PyAV/UVC) + detection math ---
av==14.2.0
numpy==2.2.4
pillow==11.1.0

# --- server link: Pi node -> WSL-SRV lane_node_server (WS client) ---
websockets==16.0

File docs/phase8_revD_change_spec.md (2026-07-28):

# Phase 8 Rev-D Lane-Controller Board — Change Specification (2026-07-19)

> **Status: SPECIFICATION — nothing implemented. This is the design document every rev-D
> implementation agent follows.**
> Scope = rev-C carryover fixes (change-list items 3 & 5) + Tier-1 diagnostics integration per
> `phase8_diagnostics_target_conditions_2026-07-19.md` §2 "Earns its place" items 1–5, plus the
> external-analog-header decision (item F below) and the OUT-B 0x23 decision (item G below).
>
> **SACRED-FILE RULE (absolute):** no rev-B/rev-C design file is edited, moved, deleted, or
> overwritten. Every script below is a COPY with `revD` in the name; every board/netlist output is
> a NEW `wsl-phase8b-revD.*` file; every fab export goes to a NEW dated directory
> (`kicad/fab_revD_YYYY-MM-DD/`). The read-only contract list is in the 2026-07-19 safeguard
> archive (`release_evidence/revC_design_snapshot_2026-07-19.zip`, 189 files hash-verified
> internally from a clean clone). `scripts/verify_revC_snapshot.py --compare-checkout`
> separately checks the 173 release-tracked paths; the 16 tool logs remain archive-only evidence.
> Reminder: **every rev-C artifact carries a revB filename** — `generate_kicad_netlist_revB.py`
> IS the rev-C generator; `kicad/fab_revB_routed_manual/` IS the rev-C-as-ordered package
> (see its `PROVENANCE.md`).
>
> **⚠️ CURRENT PACKAGE IS NO LONGER r5 — see §K.** Copper was REOPENED on 2026-07-25
> (Dylan's call: the first article should be fleet-intent, not frozen-and-bodged) and the
> r6 per-channel input protection landed on all 40 opto channels. The current package is
> **`kicad/fab_revD_2026-07-27_r10/`** (release build of the r6 design — same copper as
> `_r6/`, which is tombstoned so exactly one package is current). Everything below about
> the 47 kΩ pull-ups still holds; what changed is that `Rin`'s output is no longer the LED
> anode node. **§K is the authority for the r6 delta in this document.**
>
> **IMPLEMENTED CURRENT DELTA (2026-07-23):** exactly the 40 PC817 collector
> pull-ups `Rpu_*` (`R4,R6,…,R82`) are **47 kΩ**, not 10 kΩ. All unrelated
> 10 kΩ networks remain unchanged. (Package pointer at the time: `_r5/` —
> superseded, see above.) The binding electrical analysis and
> every-channel FA-9 acceptance are in
> `phase8_revD_remediation_spec_2026-07-21.md` §R4; that section supersedes
> older 10 kΩ PC817 arithmetic in historical review records. Its calculations
> require RP2040 GP6–GP13 PUE/PDE disabled and U1/U2 MCP23017 GPPUA/GPPUB
> commanded and read back `0x00`, so the external 47 kΩ is the sole bias.
> `R_TAPPU_*` remains an unrelated 10 kΩ diagnostic-tap drain network.

---

## 0-pre. OPEN GATES (2026-07-20 review pass — read before treating any downstream step as done)

| Gate | Status | What it blocks |
|---|---|---|
| **OG-1 — board growth 250×225 → 250×240** (§C.4 fallback 3, executed in `place_components_revD.py`) | **PENDING Dylan sign-off + enclosure re-check.** The arithmetic is verified honest (KiCad 10 DIP-4_W7.62 courtyard is 5.59 mm from the footprint file / 5.68 mm as a pcbnew bbox — either way 40 rows cannot fit 225 mm below the occupied top edge; fallbacks 1–2 are dead), but fallback 3 is conditioned on OWNER sign-off and `phase8_pair_enclosure_spec.md` still assumes 225 mm ("assumed NOT to shrink"); the rev-D bottom mounting holes moved to y=236, so the rev-C standoff/panel math no longer fits. | Step I.5 routing being treated as fab-gating; ANY enclosure, subpanel, or backplate purchase/fab. Record the sign-off in `docs/phase8_revD_run_log.md` (gate OG-1). Alternative if declined: drop to 36 rows (fits 225). |
| **OG-2 — ERC baseline waiver WVR-ERC-1** | RECORDED (run log). Exactly **1 ERC error** (Pico AGND pin 33 vs GND pin 3 POWER-OUT/POWER-OUT pin-type conflict — module-internal grounds that must be tied; benign symbol artifact) + **40 warnings**. The generator now enforces this fail-closed (`check_erc_waiver()`): any drift aborts the run. The old "0 SKiDL/ERC errors" wording in SI.1 is superseded by §I.1 below. | — (closed) |
| **OG-3 — connector cross-mate keying (J3↔J15, J13↔J16)** | Harness-BOM amendment RECORDED (§C.3 / §F): Phoenix **CP-MSTB 1734634** coding profiles at different pole positions, distinct plug colors, silk warnings on the board. The MC pin-asymmetry keying only prevents reversed insertion, NOT cross-mating of same-PN plugs. | Coding profiles must be on the harness order and FITTED before first article; first-article checklist gains a cross-mate refusal check. |
| **OG-4 — item-E hold-off proof is temperature-qualified** | Spec §E.2 CORRECTED (the 25 °C "provably OFF" claim was overbroad). Firmware must never drive GP16–GP19; disarm must drive ARM_PERMIT low, not tristate; fault-injection gate must run AT TEMPERATURE. | Item-E first-article gate is not discharged by a cold-only pass. |

---

## 0. Baseline (what rev-D starts from)

- **Netlist source of truth:** `scripts/generate_kicad_netlist_revB.py` (rev-C state, relay
  remap present at `relay_output()` lines 258–296: RAIL_EN→pad 2, coil-lo/collector/flyback
  anode→pad 5, COM/out_a→pad 1, NO/out_b→pad 3, pad 4 NC unused). 216 parts, 184 nets, 0 SKiDL
  errors (readiness checklist G3).
- **Placement source of truth:** `scripts/place_components_revB.py` — 250×225 mm, 4-layer,
  FIELD/LOGIC gutter x=76.8–80.0, LOGIC/MACHINE gutter x=181.0–184.2, opto straddle column at
  x=74 / y=24+i·6.0 (32 rows), `J_PI=(126,10,90)`, `RP_PICO=(124,55,0)` (the USB jam).
- **Netclass contract:** `scripts/apply_netclasses_revB.py` — 5 classes, every net exactly one
  class, unknown/overlap = fail. `scripts/audit_revB_board.py` asserts EXACT counts
  **Logic_Signal 80 / Logic_Power 4 / Safety_Rail 13 / Field_Sense 66 / Machine_Output 21**
  (= 184) and fails closed.
- **Isolation contract** (`phase8b_pcb_revB_netclass_creepage.md`, catalog §2 constraints 1–2):
  LOGIC↔FIELD crossings only inside PC817 packages (≥2.5 mm), LOGIC↔MACHINE only inside G5LE
  packages (≥3.2 mm); **no new isolation-barrier component class**; GND and FIELD_GND share
  zero nodes. The `.kicad_pro`/`.kicad_prl`/`.kicad_dru` sidecars travel with the board — the
  `.dru` `hasNetclass()` rules are vacuous without the class assignments (the 2026-06-03
  false-green lesson). **2026-07-21 (remediation spec §R2, closes Codex H2): 2.5/3.2 mm are
  now CONFIRMED requirements** — working voltages measured/derived (FIELD ≤ 14 V as populated
  / 34 Vpk design basis; MACHINE 24 VAC ≈ ≤ 37 Vpk per the at-machine fieldsheet), IPC-2221B
  B1 minimum 0.6 mm, ≥4×/≥5× retained margin — and the `.kicad_dru` rule values carry a
  JLC-etch-tolerance allowance on top: **2.65 / 3.35 / 1.6 mm** (as-fabbed worst case still
  ≥ 2.5 / 3.2 / ~1.5). Routed-board measured minima 2026-07-21: L↔F 2.650 mm, L↔M 3.350 mm,
  machine ch↔ch 2.325 mm.
- **Safety rail observe-only** (catalog constraint 3): never load / jumper / re-reference
  `SAFE_*` / `RELAY_ENABLE_RAIL` / `RAIL_GATE`. **There is NO RELAY_ENABLE_RAIL divider —
  a prior critic explicitly deleted it (catalog §2 item 4). Do not re-add it. VCC_5V sensing
  only.** SAFE_* loop taps (catalog §2 item 6) are **explicitly OUT OF SCOPE for rev-D** —
  FMEA-gated separate decision; no new copper on any SAFE_ net.
- **Power ground truth:** VCC_5V ≈ 4.6–4.8 V after D17 (SS14, 1 A; `06_board-power.md` §6.2.2
  and the line-118 warning); TMA-0505S wetting rail 5 V / 200 mA / 1 W with ~1.7 mA per closed
  contact; 6 relay coils ≈ 6×77 mA ≈ 460 mA (G5LE-14 ~65 Ω coil — NOT the old 40 mA G5LE-1
  figure; readiness checklist §3).

### Source-drift findings (generator wins; noted per the campaign rule)

| # | Claim in docs | Generator/board truth | Disposition |
|---|---|---|---|
| DR-1 | Catalog ground-truth line: "GP11 vacant but contested" | GP11 (Pico pin 15) is **physically wired** to the FAST_TB opto output (`FAST_INPUTS` line 99; `07_rp2040-mcp.md:97`, `12_channel-maps.md:43`). "Vacant" means *no standalone machine signal lands on it* (TB has no independent C2A cavity — SC+TB series interlock, measured 2026-06-27, `04_machine-io.md:47`) | **GP11 is NOT usable as a rev-D tap/spare GPIO.** Item E picks from the truly-unconnected pins (§E). |
| DR-2 | Change list item 5: unloaded FIELD_WET_V ≈ 14 V | Board #1 measured ~11 V (readiness checklist §4) | Known disagreement, carried per catalog §4 "known source disagreements" — per-board measurement governs the item-A verification gate. |
| DR-3 | Catalog item 4: "route Pico GP26 **+ ADC_VREF** to a … divider" | ADC_VREF (Pico pin 35) is referenced/filtered **on the Pico module itself**; it does not route to the divider | Rev-D leaves pin 35 NC (module default). Only GP26 (pin 31) lands on the divider (§D). |
| DR-4 | Catalog item 3 complexity: "~24 parts, zero new topology" | 25 parts including the mandatory new field connector, **and** the opto straddle column must be re-pitched (32→40 rows do not fit at 6.0 mm — §C.4) | Complexity is honest-moderate; the re-pitch is the one real placement pressure of the spin. |
| DR-5 | `11_connector-pinouts.md` §11.6 J5 table | Was wrong vs `SLOW_INPUT_PINS`; hand-corrected 2026-07-06 (readiness D1) but compiled `WSL_PHASE8_SYSTEM_MANUAL.md/.docx` still stale | Cite `manual_src/`, never the compiled manual, for J5/IN-B facts. |

---

## A. FIELD_WET_V bleed / minimum-load resistor

**Source:** rev-C change list item 5 (❌ not implemented — `block_supplies()` has no bleed);
catalog §2 item 1. Kills the ~11–14 V unloaded float on the unregulated TMA-0505S (U37/ISO_WET)
and the TP4 bring-up confusion.

**Value by calculation.** Budget: 2–5 mA of the 200 mA wetting rail (catalog); change list says
1 k–2.2 kΩ, ≥¼ W-class.

- Choose **R = 1.1 kΩ implemented as 2 × 2.2 kΩ in parallel** (reuses the existing 2k2 0805 BOM
  line — no new resistor value, no new footprint class).
- Steady bleed at 5 V nominal: I = 5.0 / 1100 = **4.5 mA** — inside the 2–5 mA budget (2.3 % of
  200 mA).
- Dissipation, nominal: P = 5² / 1100 = 22.7 mW total = **11.4 mW per 0805** (rated 125 mW).
- Dissipation, worst bound (the change-list 14 V float figure, which cannot persist once the
  bleed conducts but bounds the transient): 14² / 1100 = 178 mW total = **89 mW per 0805 < 125 mW
  rating** — this is why the ≥¼ W requirement is met by the parallel pair, without introducing a
  new 1206 footprint class.

**Netlist delta** (in `generate_kicad_netlist_revD.py`, inside `block_supplies()`):

| Part (tag) | Value | Footprint | Node 1 | Node 2 |
|---|---|---|---|---|
| `R_WET_BLEED1` | 2k2 | `Resistor_SMD:R_0805_2012Metric` | `FIELD_WET_V` | `FIELD_GND` |
| `R_WET_BLEED2` | 2k2 | `Resistor_SMD:R_0805_2012Metric` | `FIELD_WET_V` | `FIELD_GND` |

- **New nets: 0** (both ends land on existing nets).
- **Netclass / audit delta: none** (`FIELD_WET_V`, `FIELD_GND` are already Field_Sense).
- **Isolation:** part is entirely FIELD-domain; no barrier crossing; GND↔FIELD_GND zero-shared-node
  invariant untouched (audit invariant 5).
- **Placement:** FIELD room (left band), adjacent to ISO_WET secondary pins / TP4–TP5 area
  (≈ x 60–70, y 14–20). Never in the gutter.
- **Wetting budget delta:** +4.5 mA (see §H).

**Verification gate:** first article — TP4→TP5 unloaded reads **≤ ~6 V** (vs 11–14 V today;
per-board measurement governs, DR-2); TP4 under normal opto load still ≥ ~4.5 V; confirm bleed
current by V²/R. Regression: TP5↔TP2 still OPEN (isolation).

---

## B. Pico USB clearance from J1 (explicitly requested by Dylan)

**Source:** rev-C change list item 3 (❌ NOT done in the rev-C layout — A1/J1 byte-identical to
rev-B; the Jun-26 package re-ships the jam); catalog §2 item 2. The change list's own description:
"This rev had the USB jammed against J1 and was flashed via a hand-shaved right-angle micro-B
cable." Current hardcoded positions: `J_PI=(126,10,90)`, `RP_PICO=(124,55,0)`
(`place_components_revB.py:198,206`) — at rot 0 the Pico's micro-USB faces −y, straight into the
J1 IDC header + mated ribbon at y=10.

**SWD stays DROPPED** (Dylan 2026-06-25, change-list item 2) — do **not** silently re-add a
debug header. The compiled-OFF firmware detectors + `'?'` polarity sentinels guarantee at least
one reflash per board after Phase 0 (catalog §2 item 2), so ordinary-cable UF2 flashing is the
requirement.

**Requirement (binding):** with the board fully populated and the J1 ribbon **mated**, a standard
unmodified micro-B cable must fully seat in A1's USB receptacle. Dimensioning: micro-B receptacle
≈ 7.6 × 5.6 × 2.9 mm (Pico datasheet); commodity cable overmold **11–13 mm wide, 7–9 mm tall,
body + strain relief extending 30–35 mm** from the connector face.

**Keep-out envelope (drawn on Dwgs_User in the rev-D placement script):** a volume
**16 mm wide** (overmold + 1.5 mm/side, centered on the receptacle) × **12 mm tall** ×
**40 mm long** from the receptacle face along the plug axis, free of any component, connector
body, or mated-ribbon volume.

**Recommended placement delta (coordinates are RECOMMENDED-VERIFY — the layout agent may satisfy
the envelope differently, but the envelope, banding, and gutters are non-negotiable):**

| Tag | rev-C | rev-D recommended | Why |
|---|---|---|---|
| `RP_PICO` | (124, 55, 0) | **(92, 33, 0)** | Module spans x≈81.5–102.5 (inside LOGIC band, 1.5 mm clear of the 80.0 gutter edge), y≈7.5–58.5; USB faces the **top board edge** — the cable overmold hangs off-board, so only ~8 mm of the envelope is on-board and trivially clear. |
| `J_PWR` | (104, 10, 0) | **(113, 10, 0)** | Clears the Pico x-span + envelope (nearest body edge ≥5 mm from envelope). |
| `D_PROT` | (101, 24, 0) | **(110, 25, 0)** | Follows J_PWR; keeps the VRAW→VCC_5V run short. |
| `J_PI` | (126, 10, 90) | unchanged | Ribbon no longer in the cable path. |

> **AS-PLACED (2026-07-20, run-log COR-3):** the layout agent exercised the RECOMMENDED-VERIFY
> latitude above: `RP_PICO` landed at **(100, 33, 0)** (not (92, 33, 0) — Rpu-column courtyard
> collision, Rpu column itself moved x 92→86) and `J_PI` moved to **(135.5, 10, 90)** (+9.5 mm
> right; this table's "unchanged" describes the recommendation, not the board). Envelope,
> banding, and gutters verified intact (placement DRC 0). Pi ribbon length/dress + enclosure
> ribbon opening re-check is folded into gate OG-1.

Watch items for the layout agent: ISO_WET at (73.9, 13, 90) courtyard vs the Pico's new left
edge; J_PI footprint-origin overhang at y=10; item-D/E parts want to live near the new Pico
position (§D, §E placements already assume it).

**Affected routing region:** x ≈ 80–135, y ≈ 5–80 (I2C/UART/KICK/ARM runs from J1 to the moved
Pico; FAST_* runs from the Rpu column at x=92 now land shorter). Full re-route + re-DRC + audit
re-gate — this is a new board file anyway.

- **Netlist delta: none. New nets: 0. Class counts: unchanged.**

**Verification gates:** (1) placement review — envelope rectangle on Dwgs_User + KiCad 3D /
1:1 paper print with a real cable + ribbon-header mockup; (2) first article — off-the-shelf
micro-B cable seats with J1 ribbon mated, BOOTSEL reachable, UF2 drag-drop flash succeeds
**without** the hand-shaved cable; (3) enclosure check — cable path clear with the board mounted
(`phase8_pair_enclosure_spec.md`).

---

## C. IN-B GPB opto bank — 8 × PC817B channels (AUX4–AUX11)

**Source:** catalog §2 item 3 (breaks the ≥5-sensors-for-3-AUX-channels contention deadlock:
S/T current switches, Klixon aux contacts, door/service switches, low-rate index pulses).
GPB0–7 of MCP_IN_B (0x21) verified unconnected in the generator (`SLOW_INPUT_PINS` stops at
AUX3 on GPA7).

### C.1 Channel pattern — match `opto_input()` EXACTLY

Confirmed from the generator (lines 235–255) and `08_opto-inputs.md` §8.2: per channel
**PC817B** (UMW, LCSC C5692981, `Package_DIP:DIP-4_W7.62mm`) + **Rin 2k2** (0805, FIELD side,
from `FIELD_WET_V`) + **Rpu 47k** (0805, LOGIC side, to `VCC_3V3`). Dry-contact default: WET →
Rin → opto LED → field pin; field contact closes to FIELD_GND at the harness. Logic side pulls
the MCP pin low through the phototransistor; active-low. **No fitted RC network**
(catalog constraint 8 — debounce lives in firmware; the unavoidable first-order
47 kΩ × 50 pF receiver-node estimate is 2.35 µs).

### C.2 Netlist delta

Append to `SLOW_INPUT_PINS` (**at the END of the dict** — preserves instantiation order so
existing refdes don't shift):

| Name | MCP | MCP pin | Port/bit | New nets created by `opto_input()` |
|---|---|---|---|---|
| AUX4 | MCP_IN_B (0x21) | 1 | GPB0 (1,0) | `SLOW_AUX4`, `FIELD_SLOW_AUX4`, `FIELD_LED_AUX4` |
| AUX5 | MCP_IN_B | 2 | GPB1 (1,1) | `SLOW_AUX5`, `FIELD_SLOW_AUX5`, `FIELD_LED_AUX5` |
| AUX6 | MCP_IN_B | 3 | GPB2 (1,2) | … |
| AUX7 | MCP_IN_B | 4 | GPB3 (1,3) | … |
| AUX8 | MCP_IN_B | 5 | GPB4 (1,4) | … |
| AUX9 | MCP_IN_B | 6 | GPB5 (1,5) | … |
| AUX10 | MCP_IN_B | 7 | GPB6 (1,6) | … |
| AUX11 | MCP_IN_B | 8 | GPB7 (1,7) | … |

(MCP23017 pin map per the generator's verified comment: GPB0–7 = pins 1–8.)

**Parts: 8 × (OPTO_AUXn PC817B + Rin_AUXn 2k2 + Rpu_AUXn 47k) = 24 parts**, plus the connector
(C.3) = **25 parts**. **New nets: 24** (8 SLOW_, 8 FIELD_SLOW_, 8 FIELD_LED_).

### C.3 New field connector — J15 / `J_SLOW_IN_C`

J5 (`J_SLOWB`, 1×12) is full (11 signals + FGND pin 12). Next J number is **J15** (J1–J14
assigned; instantiate the new connector AFTER the existing seven in `block_connectors()` and
verify the emitted refdes actually lands at J15 — SKiDL assigns by order).

- Part: `Connector_Generic:Conn_01x10`, value `J_SLOW_IN_C`, tag `J_SLOWC`.
- Footprint: `Connector_Phoenix_MC:PhoenixContact_MCV_1,5_10-G-3.5_1x10_P3.50mm_Vertical`
  (`FP_MCV_1X10` — already proven on J3).
- **Pinout mirrors J3's keying pattern exactly** (8 signals + doubled field-ground last —
  J3 = signals 1–8, FGND 9–10; J5's single-FGND-last is the 11-signal variant):

| J15 pin | Net |
|---|---|
| 1–8 | `FIELD_SLOW_AUX4` … `FIELD_SLOW_AUX11` |
| 9, 10 | `FIELD_GND` |

- Mating plug: **Phoenix MC 1,5/10-ST-3,5 = 1840447** (same PN as J3's plug). **Add to the
  harness/assembly BOM in this same spec cycle** — the rev-B/-C mating-connector BOM gap
  (change-list item 4) does not get a third occurrence.
- **Cross-mate hazard + mandatory coding (gate OG-3, 2026-07-20):** J15 and J3 use the SAME
  1840447 plug on the same field edge and both wire signals 1–8 + FGND 9/10 — a swap is
  same-domain and produces NO electrical fault, but silently crosses the machine cycle sensors
  (SA/SB/SC/TA/TB/DIELL) with AUX contacts, mis-sequencing cycle control. The MC pin-asymmetry
  keying only prevents reversed insertion, not cross-mating. Harness BOM therefore carries
  **Phoenix CP-MSTB coding profiles (PN 1734634)** keyed at DIFFERENT pole positions —
  **J3: code at pole 1; J15: code at pole 10** — plus distinct plug wire-marking colors
  (J3 harness = white band, J15 = yellow band). Board silk warns at both connectors
  ("KEYED: NOT J15" / "KEYED: NOT J3"). First article: verify each coded plug physically
  REFUSES the wrong header.
  **INSTALL PROCEDURE CORRECTED 2026-07-21 (Codex H7 — the original text here had it
  REVERSED, "insert the profile in the header groove, cut the tab on the plug"): the
  CP-MSTB profile fits the PLUG (or an inverted header) — it is never pressed into a
  standard MCV G-3.5 header; the header side of the code is made by removing the coding
  rib at the matching pole. A sacrificial-pair proof (one spare plug + one scrap header,
  seat/refuse/no-damage verified against the Phoenix instruction sheet) is REQUIRED
  before coding any production part — first-article pack step FA-8
  (`docs/phase8_revD_first_article_pack.md`); harness data in
  `docs/phase8_revD_harness_bom.csv`.**
- New nets from the connector: 0 (all pins land on C.2 nets / FGND).

### C.4 Placement — the one real layout pressure (re-pitch the straddle column)

All optos must sit in the single FIELD/LOGIC gutter-straddling column (field pads left, logic
pads right — the keepout runs between the PC817 pad columns, `phase8b_pcb_revB_spec.md` 2026-06-02
re-band note). 40 rows at the rev-C 6.0 mm pitch = 234 mm — **does not fit** the 225 mm board.

- DIP-4_W7.62 courtyard along the column axis measured from the KiCad 10 footprint file:
  **5.2 mm** (−1.33…+3.87). Minimum non-overlapping pitch ≈ 5.2 mm.
- **Spec: pitch 5.25 mm, 40 rows, column start y = 14.0** → rows y = 14.0 … 218.75; Rin/Rpu
  keep their ±1.8 mm y-offsets (extents 12.2–220.55). Same x layout as rev-C (opto x=74,
  Rin x=58, Rpu x=92).
- Consequences the rev-D placement script owns: relocate the TP strip (currently y=214/221,
  x 22–164) and the bottom Dwgs/silk band; extend the gutter keepout strip to cover the longer
  column; J3/J4/J5/J15 y-positions re-align to their channel groups; J15 at ≈ (9, 200, 90).
- **Gate:** KiCad courtyard DRC clean at 5.25 mm. Fallbacks in order if it fails: (1) 5.3–5.4 mm
  pitch + reclaim the last 2–3 mm at both column ends; (2) relocate the four lamp-driver stacks
  to free bottom-band room; (3) LAST resort +10–15 mm board height — fights the shrink direction
  (catalog constraint 10) and requires Dylan's sign-off + enclosure re-check.
- **OUTCOME (2026-07-19/20): fallback 3 was TAKEN — the 5.25 mm premise above is wrong.** The
  true KiCad 10 DIP-4_W7.62 courtyard is 5.59 mm from the footprint file (5.68 mm as a pcbnew
  bounding box incl. stroke), so 40 rows need ≥ ~222.5 mm of column below an occupied top edge:
  fallbacks 1–2 are arithmetically dead. Board grown to 250×240, pitch 5.7 mm, bottom mounting
  holes now at y=236. **The required sign-off + enclosure re-check is STILL PENDING — gate OG-1.
  Alternative if declined: 36 rows fits 225 mm.**

### C.5 Class / budget / software

- **Netclass:** `SLOW_AUX*` → Logic_Signal (+8); `FIELD_SLOW_AUX*`, `FIELD_LED_AUX*` →
  Field_Sense (+16). Existing prefix rules in the classifier cover all 24 — zero classifier
  edits needed for this item; audit counts move per §H.
- **Isolation:** 8 new crossings of the EXISTING PC817 barrier class — no new `.kicad_dru`
  rules; the carried `hasNetclass()` LOGIC↔FIELD ≥2.5 mm rule binds the new nets automatically
  (because they classify into the same classes).
- **Wetting:** +8 × ~1.7 mA worst-case-all-closed ≈ +13.8 mA (catalog said 8–16 mA ✓). See §H.
- **Software companion (NOT this board task, listed for traceability):** `IN_B_MAP` + startup
  self-test extension + mid-session stuck-input coverage for IN-B ship with the spin (catalog
  §2 item 3; §1.15 mechanic-at-machine row). Lives in the separate diagnostics software
  campaign — do not touch `lane_node/`/`server/`/`tests/` or `firmware/` from this task.

**Verification gates:** footprint-vs-datasheet review re-run for PC817B DIP-4 against LCSC
C5692981 (gate 10 is per-part-class per-spin scripture, even for a reused class); SKiDL ERC 0
errors; first article — `i2cdetect` 0x21 present, then poke each of J15 pins 1–8 to FIELD_GND
and read the matching GPB bit (extends the §4 first-article input poke to all 8).

---

## D. VCC_5V board-self-health ADC divider (GP26/ADC0)

**Source:** catalog §2 item 4. Platform tier only: 5 V sag under 6-coil load (~460 mA), brownout
trending. Cannot see any FIELD/MACHINE quantity — complements machine-side sensing, never
replaces it. **Restated per the critic's deletion: there is NO RELAY_ENABLE_RAIL divider.
A divider is a permanent load on the rail and its high-side short would re-reference it,
violating observe-only. VCC_5V sensing ONLY.**

**Netlist delta** (LOGIC domain; 3.3 V-GPIO rule satisfied by the divider — VCC_5V is 5 V-domain,
catalog constraint 4):

| Part (tag) | Value | Footprint | From | To |
|---|---|---|---|---|
| `R_ADC5_TOP` | 10k | R_0805 | `VCC_5V` | `ADC_VCC5_SENSE` |
| `R_ADC5_BOT` | 10k | R_0805 | `ADC_VCC5_SENSE` | `GND` |
| `C_ADC5` | 100nF | C_0805 | `ADC_VCC5_SENSE` | `GND` |

- `ADC_VCC5_SENSE` → **Pico pin 31 (GP26/ADC0)**. Pin 35 (ADC_VREF) stays NC — module-internal
  reference (drift DR-3).
- **Sizing math:** ratio 0.5 → nominal read 4.7/2 = 2.35 V; worst-case input 5.25 V (PSU +5 %
  upstream of D17, D17 shorted-fail bound) → 2.63 V < 3.3 V full-scale, margin 20 %.
  Thevenin source impedance 5 kΩ — inside the RP2040 ADC's recommended <10 kΩ. RC corner
  1/(2π·5k·100n) ≈ 318 Hz — sag/brownout trending band; this is an ADC channel, not an
  edge-capable fast input, so the RC does not violate constraint 8.
- Permanent load on VCC_5V: 5/20k = **0.25 mA** (allowed — only SAFE_*/rail are load-forbidden).
- **New nets: 1** (`ADC_VCC5_SENSE`). **Netclass:** add exact-name entry `ADC_VCC5_SENSE` →
  Logic_Signal in the rev-D classifier (+1).
- **Placement:** LOGIC band adjacent to the moved Pico (§B), ≈ (100, 45).
- **Firmware/heartbeat consumption** (adc field on heartbeat) = software campaign, out of scope
  here; the board only provisions the channel.

**Verification gate:** first article — GP26 ADC reads VCC_5V/2 within ±3 % of the TP1 DMM value;
energize 6 coils (bench_first_article pattern) and confirm the sag is visible in the ADC trend.

---

## E. Rail-predicate edge-ordering taps — existing observable points ONLY

> **⚠ 2026-07-21 — §E.2 AND §E.3 ARE SUPERSEDED by
> `phase8_revD_remediation_spec_2026-07-21.md` §R1** (Codex NO-GO findings C1 + H1: the
> resistive taps below are bidirectional copper — a stuck-high GPIO injects into the
> observed net, and the 555 divider rides an unguaranteed VOH). The implemented rev-D
> design is the remediation spec's **per-tap 2N7002 common-source inverter** (R_TAPIN 1M →
> gate; R_TAPG 10M gate pulldown on the 3.3 V taps; VCC_3V3 → R_TAPPU 10k → drain → GPIO;
> reads INVERTED, firmware v1.2 contract R3): 15 parts, 8 new nets (4 `TAP_GATE_*` +
> 4 `TAP_*`), 680k GONE from the BOM, +1M/+10M added. Worst double-fault injection
> ≤ 0.56 µA → 0.056 V on RAIL_GATE (≥ 8× under the partial-hold onset), absolute
> transistor-free ceiling 3.3 µA. §E.1 (GPIO/pin selection), the SAFE_* scope exclusion,
> and the Safety_Rail == 13 invariant below still stand. §E.2/§E.3 text is retained for
> history only — do not implement from it.

**Source:** catalog §2 item 5 (the scope doc's tap grant): 1 ms edge-ordered capture of
**NE555_OUT, WDOG_KICK (TP8 net), ARM_PERMIT (TP13 net), RP2040_OK (TP14 net)** via spare RP2040
GPIOs — records ordered predicate transitions for advisory cause inference (wdt_reset
vs pi_death vs arm_drop) only when independent evidence proves an actual rail drop. None
directly observes `RELAY_ENABLE_RAIL`/TP16 or proves Q14/J14/rail stuck-on or
stuck-open behavior. **Explicitly OUT OF SCOPE: any new connection to SAFE_TBSC_RETURN /
SAFE_STOP_RETURN / any SAFE_* loop net** (catalog §2 item 6 — FMEA-gated separate decision;
SAFE_TBSC_RETURN has no test pad today and gets no new copper in this spin). Also out of scope:
anything touching RELAY_ENABLE_RAIL / RAIL_GATE.

### E.1 GPIO selection

Truly-unconnected Pico pins per the generator (only 1, 2, 4, 9–12, 14–17, 36, 39 + grounds are
used): GP3, GP4, GP5, GP14, GP15, **GP16, GP17, GP18, GP19**, GP20, GP21, GP22, GP26, GP27,
GP28 (~15, as the catalog says). **GP11 is NOT spare — it is FAST_TB (drift DR-1).** GP26 is
consumed by item D. Pick the contiguous block:

| Tap net | Source net | GPIO | Pico pin |
|---|---|---|---|
| `TAP_NE555_OUT` | `NE555_OUT` (5 V domain) | GP16 | 21 |
| `TAP_WDOG_KICK` | `WDOG_KICK` (3.3 V, Pi-driven) | GP17 | 22 |
| `TAP_ARM_PERMIT` | `ARM_PERMIT` (3.3 V, Pi-driven) | GP18 | 24 |
| `TAP_RP2040_OK` | `RP2040_OK` (3.3 V, Pico-driven) | GP19 | 25 |

### E.2 Tap networks + the can't-assert/can't-hold proofs — **SUPERSEDED (see §E banner; remediation spec R1)**

**3.3 V taps (WDOG_KICK, ARM_PERMIT, RP2040_OK): single series 680 kΩ, no shunt, Schmitt-mode
GPIO input.** A divider would put the read below VIH on an already-3.3 V net; the task's
"divider" requirement is satisfied where it electrically applies (the 5 V NE555_OUT tap) and by
the series-only proof below where a shunt would break reading.

- *Worst credible tap fault = GPIO stuck driving 3.3 V.* The sensitive victims are the rail
  AND-chain bases: ARM_PERMIT and RP2040_OK each feed `Rb_AND_* = 10k` into an MMBT3904 base
  with `Rpd_AND_* = 100k` to GND (generator `block_rail()` lines 503–510). With the legitimate
  driver tristated (Pi rebooting — exactly the window that matters), the injected base voltage
  is the three-resistor ladder: V_base = 3.3 × 100k / (680k + 10k + 100k) = **0.42 V**.
  **TEMPERATURE QUALIFICATION (2026-07-20 correction — the original "< any silicon V_BE
  turn-on → provably OFF" claim only holds near 25 °C):** at 25 °C the MMBT3904 collector
  current at V_BE 0.42 V is ~0.1 µA (harmless), but V_BE(on) falls ~2 mV/K, so at ~85 °C
  junction the same 0.42 V drives roughly **5–30 µA** — and only ~5–13 µA through the 100k
  `R_RAIL_GATE_PULLUP` spans the AO3401's full V_GS(th) range (−0.5…−1.3 V), so a stuck-high
  tap CAN hold (or partially hold, relay-brownout class) the pass-FET at temperature, with
  weak-conduction onset around 70–75 °C. A 100k-class series still fails even at 25 °C
  (V_base ≈ 0.9 V) — **hence 680 k, not 100 k; do not "simplify" this value down.** The
  residual hot-tap-fault risk is closed procedurally, all BINDING: **(1)** firmware must
  NEVER configure GP16–GP19 as outputs (inputs + Schmitt only; assert in firmware review);
  **(2)** a deliberate disarm must DRIVE ARM_PERMIT low (push-pull — the tap then injects
  ≤0.25 mV and hold-off is unconditional), never tristate; **(3)** the fault-injection gate
  below runs AT TEMPERATURE, not just cold. Option evaluated but NOT taken this spin (it is a
  safety-rail value change requiring its own observe-only-contract review):
  `R_RAIL_GATE_PULLUP` 100k→22k, raising the required hold-off current ~5×.
  - WDOG_KICK victim is the AO3400 kick-gate ladder (1k + 10k pd): V_gate = 3.3 × 10k/(680k+11k)
    ≈ **0.05 V** « 0.65 V min V_GS(th) ✓.
  - When the legitimate driver is active (push-pull ~50 Ω): tap fault contributes
    3.3 V/680k ≈ 4.9 µA → ≈0.25 mV of disturbance ✓ (can neither assert nor hold).
- *Reading integrity through 680 k:* RP2040 leakage ±1 µA worst → ±0.68 V error.
  High: 3.3−0.68 = 2.62 V > VIH 2.0 V ✓. Low: 0.68 V < VIL 0.8 V ✓. Enable the pad Schmitt
  trigger. Timing: 680k × ~10 pF pin ≈ 7 µs — far inside the 1 ms ordering requirement and not
  a masking RC on any machine-edge channel (constraint 8 untouched — these taps are not machine
  inputs).

**NE555_OUT tap (5 V domain — divider mandatory per constraint 4):** series **100 kΩ** + shunt
**680 kΩ** to GND (ratio 0.872).

- NE555 (bipolar, VCC ≈ 4.7 V) output high ≈ VCC−1.2…1.7 ≈ 3.0–3.5 V → read 2.6–3.05 V > VIH ✓.
  **Worst-case bound (COR-2, 2026-07-20 — the original "≤ 3.27 V < 3.3 V" line assumed
  VOH ≤ 3.75 V and was optimistic):** absolute worst rail 5.25 V at light load (Thevenin ≈ 87k
  is µA-class for the 555) gives VOH up to ≈ VCC−1.2 ≈ 4.05 V → read ≈ 4.05 × 0.872 ≈
  **3.53 V**. That exceeds VDD 3.3 V but stays below the RP2040 3.6 V absolute maximum, and the
  ≥ 100 kΩ source impedance bounds any pad-clamp current to single-digit µA — electrically
  safe, but do not quote the old 3.27 V figure. (A plain wire or a 2:1 divider still fail
  here — this ratio remains deliberate.) Low ≈ 0.25 V → 0.22 V ✓.
  Thevenin ≈ 87k → leakage error ±0.09 V ✓.
- *Can't-assert proof:* NE555_OUT is a push-pull mA-class output; a faulted GPIO injects at most
  3.3 V/100k = 33 µA — 2+ orders below the 555's drive. ✓
- 680k appears in both tap flavors → **one new BOM value total (680k 0805)**.

### E.3 Netlist delta — **SUPERSEDED (see §E banner; implemented delta = remediation spec §R1.7)**

Historical (NOT implemented):

| Part (tag) | Value | From | To |
|---|---|---|---|
| `R_TAP_555` | 100k | `NE555_OUT` | `TAP_NE555_OUT` |
| `R_TAP_555_DIV` | 680k | `TAP_NE555_OUT` | `GND` |
| `R_TAP_KICK` | 680k | `WDOG_KICK` | `TAP_WDOG_KICK` |
| `R_TAP_ARM` | 680k | `ARM_PERMIT` | `TAP_ARM_PERMIT` |
| `R_TAP_RPOK` | 680k | `RP2040_OK` | `TAP_RP2040_OK` |

Implemented instead (remediation spec §R1.7, 2026-07-21): per tap suffix in
{555, KICK, ARM, RPOK} — `R_TAPIN_*` 1M (observed net → `TAP_GATE_*`), `Q_TAP_*` 2N7002
SOT-23 (G=`TAP_GATE_*`, S=GND, D=`TAP_*`), `R_TAPPU_*` 10k (VCC_3V3 → `TAP_*`), plus
`R_TAPG_*` 10M (`TAP_GATE_*` → GND) on KICK/ARM/RPOK only (the 555's push-pull output is
never high-Z; asymmetry deliberate). Tap drain nets land on Pico pins 21/22/24/25 per E.1.
**New nets: 8. Parts: 15. 680k leaves the BOM entirely.**

- **Netclass:** add prefix rule `TAP_` → Logic_Signal in the rev-D classifier (+4). All tap
  copper is LOGIC-band only; nothing crosses a barrier; Safety_Rail count stays EXACTLY 13
  (design invariant of this spin — any Safety_Rail delta in the audit = automatic fail).
- **Placement:** series resistor within ~10 mm of its source node (the long trace to the GPIO is
  then the low-energy, high-impedance side); cluster ≈ x 130–170 / y 35–80 near the watchdog
  block; tap runs to the moved Pico (§B).
- **Firmware consumption** (1 ms edge capture + rail-drop-reason codes on heartbeat) = later
  campaign; `firmware/` untouched by this task.

**Verification gates:** bench — scope each TAP_ node vs its source for level/threshold margins;
fault-injection test: force each tap GPIO output-high (test firmware) with the Pi link disconnected
and prove the rail does NOT arm and an armed rail still drops on Pi-kill within the same time as
an untapped board; then a forced Pi-death and a forced kick-starvation each produce the correct
edge ORDER on the four taps. **AT-TEMPERATURE repeat (mandatory, gate OG-4): re-run the
stuck-high fault injection with the Q_AND_ARM / Q_AND_RP_OK / Q_RAIL region held ≥70 °C case
temperature (heat gun + thermocouple) and prove a deliberate ARM_PERMIT disarm still drops the
rail — a cold-only pass does not discharge this gate.**

---

## F. External-analog expansion header — J16 / `J_EXT_I2C` (decision: dedicated header, ADD)

**Source:** catalog §2 "Do NOT put on the board" (isolated analog front-end = permanently
external — a third barrier class is forbidden) + §3 item 4 (USB-ADC is the mandatory analog
path). This header is the *integrate-without-a-barrier-class* answer: a keyed LOGIC-domain
connector so a future **externally-isolated** ADC/sensor module (its isolation lives ON the
module, off-board) can plug in with no on-board analog front-end.

**J1-suffices evaluation (required by the task): J1 does NOT suffice — decision justified.**
J1 exposes SDA/SCL/3V3/5V, but the J1 header is fully occupied by the mated Pi ribbon; its
unconnected pins 14–20 sit inside the mated IDC shroud and are physically unavailable. Tapping
the ribbon mid-run is a field-hack, not an integration point. A dedicated header costs one
proven-footprint part and zero new nets. **Decision: add J16.** (This also makes item G
redundant — see §G.)

**Netlist delta:** one part — `Conn_01x06`, value `J_EXT_I2C`, tag `J_EXTI2C`, footprint
`Connector_Phoenix_MC:PhoenixContact_MCV_1,5_6-G-3.5_1x06_P3.50mm_Vertical` (`FP_MCV_1X06`,
proven on J13). Instantiate after J15 → refdes **J16** (verify emitted refdes). Mating plug
Phoenix MC 1,5/6-ST-3,5 = **1840405** (same PN as J13's plug — add to harness BOM now).

| J16 pin | Net | Note |
|---|---|---|
| 1 | `VCC_5V` | module primary power — **budget cap 45 mA** (R3-7 re-derivation; was 100 mA), re-run §H D17 math before any module lands |
| 2 | `GND` | |
| 3 | `I2C_SDA` | shared bus 1 (existing 4.7k pullups) |
| 4 | `I2C_SCL` | |
| 5 | `VCC_3V3` | logic-reference option for the module's isolated-side interface |
| 6 | `GND` | pin-1-vs-6 asymmetry + MC keying = polarization (reversed-insertion only — see coding note below) |

- **Cross-mate hazard + mandatory coding (gate OG-3, 2026-07-20):** J16 and J13 use the SAME
  1840405 plug 24 mm apart on the same board edge, and pins 1/2 are VCC_5V/GND on BOTH — a
  swapped lamp harness in J16 lands the mask LED wired to plug pin 6 straight across
  VCC_5V→GND with NO series resistor (the 330R limiters sit on-board behind J13), and the LEDs
  on pins 3/4 drag SDA/SCL to ~3 V, wedging the I2C bus that drives MCP_OUT_A — the relay
  expander then holds its last-written state while the controller is blind. Harness BOM
  carries **CP-MSTB 1734634** coding at DIFFERENT pole positions — **J13: code at pole 1;
  J16: code at pole 6** — plus distinct plug colors (J13 harness = white band, J16 = blue
  band). Board silk warns at both connectors ("KEYED: NOT J16" / "KEYED: NOT J13 LAMP").
  First article: verify each coded plug physically REFUSES the wrong header. The prior
  "pin-1-vs-6 asymmetry + MC keying = polarization" claim only ever covered reversed insertion.
  Install procedure per the corrected §C.3 rule (2026-07-21, Codex H7): profile in the PLUG,
  never a standard header; header-side rib removed at the matching pole; sacrificial-pair
  proof (FA-8) before coding production parts.

- **Shared vs dedicated bus:** shared. Address space check: on-bus today 0x20/0x21/0x22, with
  0x23 reserved for a future OUT-B (generator comment line 529). Typical ADC modules land at
  0x40–0x4B (INA219/ADS1115 class) — no conflict. **Rule: any module on J16 must avoid
  0x20–0x23.**
- **New nets: 0. Netclass delta: 0** (all five pins are existing nets). DNP-tolerant by nature —
  an empty or unused header is electrically inert; populate on first articles, fleet decision
  later.
- **Placement:** LOGIC band bottom edge ≈ (155, 206, 0) (clear of J13 at 104 and the lamp-driver
  stacks). Keep the added SDA/SCL stub < 150 mm; bus load delta ~+20 pF on a 100 kHz bus with
  4.7k pullups — comfortably inside 400 pF.
- **Isolation:** header is 100 % LOGIC domain. Any module plugged here must carry its own
  isolation for anything it touches beyond LOGIC — that stays the module's problem, never new
  board copper (no new barrier class, constraint 1 upheld).

**Verification gate:** i2cdetect with a scrap ADS1115/INA219 module on J16 shows the module AND
0x20/0x21/0x22 all still ACKing; bus rise-time spot-check with the module attached.

---

## G. OUT-B MCP23017 @0x23 footprint — decision: DEFER (do not place)

**Source:** catalog "Nice-to-have" table — "Pindicator lamps only — **zero diagnostics yield**;
no condition in §1 consumes OUT-B. Capacity insurance."

**Evaluation against "include only if genuinely trivial":** the generator cost is 3 lines
(`block_mcp("MCP_OUT_B", (1, 1, 0), None)` — A0+A1 high per the generator's own 0x23 comment),
but the REAL cost is not the generator: an SOIC-28 + decoupling in the center band + I2C stub +
32 dead pins of routed-around copper on a board whose standing direction is SHRINK (catalog
constraint 10), plus ERC/audit noise from a fully-unconnected GPIO field, for a function (lamp
drive) that would still need ~11 driver parts per channel and a connector to be usable.
**And item F now provides the same capacity insurance off-board:** a $2 MCP23017 breakout on
J16 at the very same 0x23 address delivers OUT-B the day it's ever wanted, with zero board area.

**Decision: DEFER.** Rev-D carries only the documentation note (the 0x23 strap comment already
in the generator). If Dylan overrides: the delta is +2 parts (MCP_OUT_B + C_MCP_OUT_B), 0 new
nets, 0 class-count change, and the SKiDL ERC unconnected-pin warnings must be explicitly
waived in the run log.

---

## H. Summed budgets

### H.1 Audit class-count delta table (extend `apply_netclasses_revD.py` + `audit_revD_board.py` in lockstep)

2026-07-21 (remediation spec §R1.7): item E's delta is now **+8 nets** (4 `TAP_*` drain
nets + 4 `TAP_GATE_*` gate nets), all Logic_Signal via the `TAP_` prefix rule:

| Class | rev-C (asserted today) | A | B | C | D | E (R1) | F | G | **rev-D expected** |
|---|---|---|---|---|---|---|---|---|---|
| Logic_Signal | 80 | — | — | +8 | +1 | +8 | — | — | **97** |
| Logic_Power | 4 | — | — | — | — | — | — | — | **4** |
| Safety_Rail | 13 | — | — | — | — | **0 (invariant)** | — | — | **13** |
| Field_Sense | 66 | — | — | +16 | — | — | — | — | **82** |
| Machine_Output | 21 | — | — | — | — | — | — | — | **21** |
| **Total nets** | **184** | | | +24 | +1 | +8 | | | **217** |

Classifier edits required in the rev-D copy: exact-name `ADC_VCC5_SENSE` → Logic_Signal;
prefix `TAP_` → Logic_Signal. Everything else classifies under existing rules. The rev-D audit
script asserts `{Logic_Signal: 97, Logic_Power: 4, Safety_Rail: 13, Field_Sense: 82,
Machine_Output: 21}`, `Default == 0`, zero `N$*` anonymous nets, 217 total — fails closed,
same as rev-C. **A Safety_Rail count ≠ 13 is an automatic stop-ship.**

### H.2 New-part count

| Item | Parts |
|---|---|
| A — bleed | 2 |
| B — USB clearance | 0 |
| C — GPB opto bank + J15 | 25 |
| D — VCC_5V ADC | 3 |
| E — taps (remediation spec R1: 4 × unidirectional stage) | 15 |
| F — J16 | 1 |
| G — deferred | 0 |
| **Total** | **46** → part registry 216 → **262** |

New BOM lines (2026-07-21, R1): **1M 0805** and **10M 0805** (+2 values; the earlier plan's
680k is GONE — the taps were its only use). New footprint classes: **none** (2N7002 SOT-23 is
the existing `Qled_*` class; 2k2/10k/100k/0805/DIP-4/MCV_1x10/MCV_1x06 all already on the
board) — but gate 10 datasheet review re-runs per part class anyway (§I step 2; run-log FR-8
covers 2N7002-in-SOT-23, FR-9 the `_D1.4` MCV drill/pad change per remediation spec R2.5).

### H.3 Wetting-rail budget (TMA-0505S, 5 V / 200 mA / 1 W)

| Load | Current (worst case, all contacts closed) |
|---|---|
| 32 existing channels × ~1.73 mA ((5−1.2)/2k2) | 55.4 mA |
| 8 new channels (item C) | +13.8 mA |
| Bleed (item A) | +4.5 mA |
| **Total** | **73.7 mA = 37 % of 200 mA** ✓ |

Output power 5 V × 73.7 mA ≈ 0.37 W of 1 W ✓. Reminder from the catalog critic (finding 10):
machine sensors are POWERED by the shared machine-side 24 VDC supply, never by FIELD_WET_V —
the wetting rail only wets dry/NPN contacts.

### H.4 D17 (SS14, 1 A) budget

Baseline worst case ~0.7–0.9 A (catalog constraint 7; `06_board-power.md:118-120` warning).
Rev-D additions on VCC_5V:

| Source | Δ |
|---|---|
| TMA input for +18.3 mA of new secondary load (bleed + 8 channels), η≈0.75, Vin≈4.7 V | ≈ +26 mA |
| 8 new 47k logic pull-ups (all optos on) via Pico 3V3 | ≈ +0.56 mA |
| ADC divider | +0.25 mA |
| Taps (R1 stages, 2026-07-21: 4 × 10k drain pull-ups, worst = all four observed nets high → FETs on, 4 × 0.33 mA on VCC_3V3 through the Pico regulator) | ≈ +1.3 mA |
| **Total Δ** | **≈ +29 mA** |

New worst case ≈ **0.73–0.93 A — still under 1 A but the margin was already thin and rev-D
consumes ~3 % more**. **IMPLEMENTED in the rev-D generator (2026-07-20, run-log FR-3): `D_PROT` value
is now SS34 (3 A)** — a value swap, zero copper change, same `D_SMA` footprint. Gate-10
footprint-vs-datasheet check DONE: chosen MPN **MDD SS34, LCSC C8678, package SMA/DO-214AC
verified** (SS34 also ships in SMB/SMC from other vendors — exactly the G5LE-1/-14 class of
trap; do not substitute MPNs without re-running gate 10). The diff-script contract whitelists
this one value change (`ALLOWED_CHANGED_PARTS`).

**J16 module allowance — RE-DERIVED (R3-7, 2026-07-21; was 100 mA):** the earlier
"sanctioned 100 mA module allowance" silently used the 1206L020 **23 °C** hold (0.20 A ×
½ = 100 mA "2× margin"). That margin evaporates at temperature. Littelfuse 1206L020
still-air hold-current derating: 0.17 A @40 °C, 0.15 A @50 °C, **0.12 A @70 °C, 0.09 A
@85 °C**. The declared worst-case F1 body temperature is **85 °C** — enclosure spec
`phase8_pair_enclosure_spec.md` gives ≤ ~48 °C internal *bulk* air (35 °C summer + ΔT ≈
8 °C, sealed no-vent), and F1 sits in that volume next to the dominant heat sources
(Pi + heatsink, TMA-0505S brick, energized relay coils), so we derate at the datasheet's
characterized ceiling (85 °C) to envelope any local hotspot rather than model it (48 °C
bulk interpolates to ~154 mA hold for reference). Applying the required **≥ 2× hold
margin at 85 °C: allowance = 90 mA / 2 = 45 mA.** PPTC *trip* is a minimum-to-trip, not a
hard cap; sizing the steady module draw well under I_hold(T) is what keeps a legitimate
hot module from nuisance-tripping. **F1 selection is UNCHANGED** (1206L020YR still trips
a shorted module inside the SS34 budget); the reduced 45 mA allowance takes the D17 worst
case to ~**0.775–0.975 A**, which only *widens* the SS34 margin — it does not reopen the
SS14 decision. **If any J16 module (≤ 45 mA cap) ever populates, re-run this table anyway.**

**Polyfuse — TAKEN (Codex R2-4, round 2):** the "open option" below is now the fitted
F1 (`1206L020YR`, VCC_5V → J16 pin 1) plus the TCA4307/SRV05-4/JP1 stack. Historical
note retained: *the pre-round-2 spec listed a series polyfuse as an untaken option.*
Any F1 substitute must have **minimum Ihold at 85 °C ≥90 mA**. Matching the
nominal trip current is not sufficient: PPTC trip behavior depends on time and
temperature and is not a hard current clamp.

**rev-D.1 upgrade path (recorded, NOT this spin — needs copper):** replace the PPTC + ESD
with a current-limiting **eFuse / e-load-switch that has a hardware-programmable current
limit AND an open-drain FAULT flag routed to a spare RP2040 GPIO** (part class: TI
**TPS2660** industrial eFuse w/ /FLT, TI **TPS25200** 5 V eFuse w/ FAULT, or Nexperia
NX5P-class), so a wedged/over-drawing J16 module becomes a firmware-diagnosable event
rather than a silent trip with a long PPTC reset tail.

---

## I. Ordered implementation sequence (each step gates the next)

All new files; nothing existing is edited. Python on this laptop: `py -3` (the `python` MS-Store
stub trap). pcbnew steps run under KiCad 10's bundled python
(`C:\Program Files\KiCad\10.0\bin\python.exe`) — see `project_phase8a_pcb_toolchain` gotchas.

1. **Netlist:** copy `scripts/generate_kicad_netlist_revB.py` → `scripts/generate_kicad_netlist_revD.py`.
   Apply §A/§C/§D/§E/§F deltas (append-only ordering per §C.2/§C.3). Update the docstring +
   silkscreen-facing rev strings to REV-D. Output to **`kicad/wsl-phase8b-revD.net`** (new
   filename — never overwrite `wsl-phase8b.net`). Expect: **252 parts, 213 nets**
   *(original items-A–G figures; **262 parts / 217 nets** after remediation spec R1.7 —
   the implemented state)*, **0 netlist-generation errors; ERC = exactly 1 waived error
   (WVR-ERC-1, the Pico AGND/GND POWER-OUT pin-type artifact) + 40 baseline warnings —
   enforced fail-closed by the generator's own `check_erc_waiver()`; any drift aborts** (supersedes the earlier
   "0 SKiDL/ERC errors" wording — the rev-C generator never ran ERC, so rev-D defines the
   baseline; see gate OG-2). Confirm J15/J16 refdes landed as specified; the emitted sklib
   will be `generate_kicad_netlist_revD_sklib.py` (new file, fine).
2. **Footprint-vs-datasheet gate (rev-C process item 10 — scripture):** per part class touched:
   PC817B vs LCSC C5692981 pad map; MCV 1x10 / 1x06 vs Phoenix 1840447/1840405 mating; 0805
   passives; SS34-in-SMA (the D17 swap IS taken — MDD C8678 SMA verified). Record the review
   in the run log — **`docs/phase8_revD_run_log.md` (created 2026-07-20; the gate had run
   without a recorded artifact — do not let that recur)**. Regression:
   K1–K7 relay map unchanged from G1/G2 (pads 2/5 coil, 1 COM, 3 NO, 4 NC).
3. **Placement:** copy `place_components_revB.py` → `place_components_revD.py`; point it at the
   revD netlist and output **`kicad/wsl-phase8b-revD.kicad_pcb`**; apply §B moves + §C.4
   re-pitch + new-part placements (§A/§D/§E/§F) + USB keep-out drawing + TP-strip relocation +
   REV-D silkscreen ID. **Copy** `kicad/wsl-phase8b.routed-manual.kicad_pro/.kicad_prl/.kicad_dru`
   to `wsl-phase8b-revD.*` sidecar names (sidecars travel with the board; the .dru carries the
   isolation rules).
4. **Netclasses:** copy `apply_netclasses_revB.py` → `apply_netclasses_revD.py`; add the two
   classifier edits (§H.1); run — must print 93/4/13/82/21 *(now **97/4/13/82/21** post-R1.7)*
   with zero unknown/overlap.
5. **Route:** copy `manual_route_revB.py` / `export_specctra_revB.py` → revD names as needed;
   re-route (the §B region is a full re-route anyway). DRC with the carried .dru: 0 violations /
   0 unconnected / 0 footprint errors.
6. **Audit:** new `audit_revD_board.py` (copy of the revB auditor) with expected counts
   {93, 4, 13, 82, 21}, 213 nets *(now {97, 4, 13, 82, 21}, 217 nets post-R1.7)*, plus the
   carried invariants: Default==0, no N$*, rail reaches
   exactly 7 K-coils + pass-FET, no OUT_* on the Pico, GND/FIELD_GND distinct with zero shared
   nodes, SAFE_ nets present with **no new pads beyond rev-C's membership** (guards §E scope),
   M1 channel still DNP. ALL PASS required.
7. **Fab export:** new `export_fab_revD.py` — REV and output dir are PARAMETERS; writes ONLY to
   **`kicad/fab_revD_<date>/`**; **refuses to run if the output dir exists** (no rmtree of
   anything, ever — change-list item 12, the rmtree incident). Package manifest carries
   sha256 + `generated_at` + source-board name like the rev-C package.
8. **Gerber manual inspection** (G5 pattern): K1–K7 pad-net map on the plots; new opto-bank and
   J15/J16 pads; USB keep-out visually clear; JLC upload preview vs this spec before paying.
9. **First-article gate** (extend the readiness-checklist §4 per-board pass): rails incl.
   **TP4 ≤ ~6 V unloaded (item A)**; i2cdetect 0x20/0x21/0x22; 6-relay make/break; ordinary
   micro-B cable seats + UF2 flash with ribbon mated (item B); 8 × GPB input pokes (item C);
   GP26 ≈ VCC_5V/2 ±3 % and coil-load sag visible (item D); tap levels + fault-injection +
   forced rail-predicate edge ordering (item E; causal predicates only, not direct
   `RELAY_ENABLE_RAIL`/TP16 observation); J16 bus check with a scrap module (item F).
   One channel of each NEW I/O type energized before trusting the board (process item 11).
   The generated pack also carries two system-level gates that bare-board tests
   cannot discharge: FA-13 keeps physically open J14.3–4 installation-NO-GO
   until an approved Stop/control-power interface is landed, proves bounded
   Stop→power-drop behavior, and closes the lane-21/22 pit-interlock disposition.
   Those lanes have no C.I.S.; any installed/new pit interlock is tested
   separately in its approved upstream safety-disconnect path, because J14-only
   gating cannot replace a final disconnect. FA-14 requires
   qualified-electrician/listed-tester protective-earth and hot/neutral
   polarity proof. Neither mains nor PE-test current may enter Rev-D.

---

## J. Item-to-source citation index

| Item | Primary sources |
|---|---|
| A | change list §5; catalog §2 item 1; readiness §4 (11 V measurement); generator `block_supplies()` 454–469 |
| B | change list §3 (+§2 SWD DROPPED); catalog §2 item 2; `place_components_revB.py:198,206`; readiness §3 consumables note |
| C | catalog §2 item 3; generator `opto_input()` 235–255 + `SLOW_INPUT_PINS` 105–130 + `block_connectors()` 367–451; `08_opto-inputs.md` §8.2/§8.4; readiness §3 (Phoenix PNs), change list §4 (BOM-gap lesson) |
| D | catalog §2 item 4 (incl. the critic's RELAY_ENABLE_RAIL-divider deletion); `06_board-power.md` §6.1–6.2; generator `block_rp2040()` |
| E | catalog §2 item 5 (grant) + item 6 (SAFE_* exclusion) + §1.15; generator `block_watchdog()` 317–364 + `block_rail()` 472–511; `place_components_revB.py` TP list 339–360; `10_watchdog-rail.md` |
| F | catalog §2 "Do NOT" (external analog, permanently) + §3 item 4; generator J_PI wiring 401–412 (J1 fully consumed); 0x23 comment line 529 |
| G | catalog "Nice-to-have" OUT-B row (zero diagnostics yield); constraint 10 (shrink) |
| H/I | `apply_netclasses_revB.py` / `audit_revB_board.py` (counts + fail-closed pattern); change list §10–12 (process gates); `phase8b_pcb_revB_spec.md` (netclass history, 184-net baseline) |

---

## K. r6 — per-channel input protection on all 40 opto channels (**IMPLEMENTED 2026-07-25**)

**Decision record.** Copper for rev-D was frozen after r5. On **2026-07-25 Dylan reopened
it**, with the reasoning recorded verbatim in the run log: he wants the first-article order
to be **as close to fleet-intent as possible rather than freezing and bodging**, and the
schedule risk on this program is **bench time, not design time** — rev-C's bench campaign
is done (6/6 relays, GS map 10/10, all six rail conditions drop TP16 independently, NE555
≈10 s, max-run ≈9 s, lamps 4/4), so a copper iteration costs days of CAD, not weeks of
bring-up. The fab order still goes out this week.

**Full authority: `docs/phase8_revD_r6_input_protection_spec_2026-07-25.md`.** This section
is the change-spec-level summary and the pointer; it does not restate the derivations.

### K.1 What changed

`opto_input()` was one hardcoded topology for all 40 channels, and it had **no series
blocking diode, no reverse clamp, and no filter position**:

```
before:  FIELD_WET_V -> Rin (2k2) -> [PC817 LED] -> field pin           (2-node FIELD_LED_<n>)
after:   FIELD_WET_V -> Rin (2k2) -> FIELD_RIN_<n> -> [Dser] -> FIELD_LED_<n>
                                     -> [PC817 LED] -> field pin
                                     with [Dclamp] anti-parallel across the LED,
                                     and a DNP logic-side Cflt (opto collector -> GND)
```

- **`Dser_<n>`** — 1N4148WS SOD-323, series block, **ALWAYS POPULATED**. Anode on
  `FIELD_RIN_<n>`, cathode on `FIELD_LED_<n>`.
- **`Dclamp_<n>`** — 1N4148WS SOD-323, **anti-parallel across the LED**, populated.
- **`Cflt_<n>`** — 0805 X7R, **DNP by design**, logic side. 10 nF on the 8 RP2040 fast
  channels, 2.2 µF on the 32 MCP23017 slow channels.
- Refdes: `D18`–`D97` (diodes) and `C17`–`C56` (caps), all appended by
  `block_input_protection()` which runs **last**, so **no pre-existing refdes moves** —
  `EXPECTED_OPTO_PULLUPS = {R4, R6, …, R82}` and seven manual chapters stay valid.

### K.2 Why both provisions, and why neither is DNP

- **A clamp alone is not sufficient.** On the reverse half-cycle it conducts and backfeeds
  `Rin` into the **shared** `FIELD_WET_V` rail, which the unregulated TMA-0505S cannot
  sink: the self-consistent solve pulls `Vw` to **10.77 V at 9.79 mA** on a 33 VDC PBZ
  channel — one over-voltage channel corrupting the wetting rail for **all 40**.
- **A series diode alone is not sufficient.** It leaves the LED's reverse voltage set by a
  **leakage divider** (diode ≈ nA vs LED I_R 10 µA @ 4 V) — correct by an unspecified
  parameter ratio rather than by construction. The clamp is what pins it at ≈ 0.35 V.
- **The series position is never DNP-empty** — that leaves the channel **open-circuit**.
  The "0 Ω link now, diode later" plan from the recommendation doc was **rejected twice
  over**: a 0 Ω is an `R`-prefix part (40 of them shift every resistor above R3 and break
  the pull-up gate), and 0805 (pads ±0.913 mm) and SOD-323 (pads ±1.05 mm) **cannot share
  a land**, so the swap does not survive contact with a real footprint.
- **The clamp is populated, not DNP.** With `Dser` fitted it carries leakage only (≤ 15 µA),
  so it is a *voltage-defining* element, not a current path; it costs $0.32/board, needs no
  `PART_LOCK` change, and it removes the per-channel stuffing table that the recommendation
  itself objected would be "easy to lose across 32 lanes".

### K.3 What it cost

| | before r6 | after r6 |
|---|---|---|
| Netlist parts / DNP / placed / JLC-placed | 271 / 28 / 243 / 226 | **391 / 68 / 323 / 306** |
| Named nets | 223 | **263** (+40 `FIELD_RIN_*`) |
| `Field_Sense` netclass | 82 | **122** |
| **`Safety_Rail` netclass** | **13** | **13 — UNCHANGED (stop-ship if it ever drifts)** |
| JLC assembled part **lines** | 27 | **27** — the 80 diodes join the existing 1N4148WS line (qty 8 → 88) |
| CTR margin at the MCP V_IL sink | 22.3× | **≈ 17× worst-case** (the 47 kΩ pull-up had already paid for the diode) |
| `FIELD_WET_V` load | 74.5 mA (37 %) | **58.1 mA (29 %)** — *lower*; current was never the constraint |
| Board outline | 250 × 240 mm | **250 × 240 mm — unchanged**, `INPUT_PITCH` 5.700 mm unchanged, the 0.02 mm opto-row slack never touched |

`Rin` **stays 2k2** (Option A′ 1k8 was considered and rejected — the pull-up already bought
the margin). Firmware was **not touched and not flashed**.

### K.4 The one thing r6 does NOT fix

A cam channel driven by the machine's 24 VAC ladder becomes **electrically survivable**
(28.9 V peak vs the 1N4148WS 75 V V_RRM) but **not functionally usable**: both half-cycles
(7.9 / 8.7 ms) clear `DEBOUNCE_CAM_US` = 2 ms, so 120 debounced edges/s = **12 per
`CHATTER_WINDOW_MS`** against `CHATTER_MAX_CAM` = 8 → a continuous chatter fault. Worse,
the four AC-suspect cams (SA/SB/TA1/TA2) are **fast** channels, so the 2.2 µF integration
route is unavailable to exactly the channels most likely to need it (≥ 951 nF ⇒ 183 ms
de-assert vs a 1 ms edge budget). Closing that needs a **firmware** change (out of scope)
or the metering-guide fallback: **tap those cams at the switches**.
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

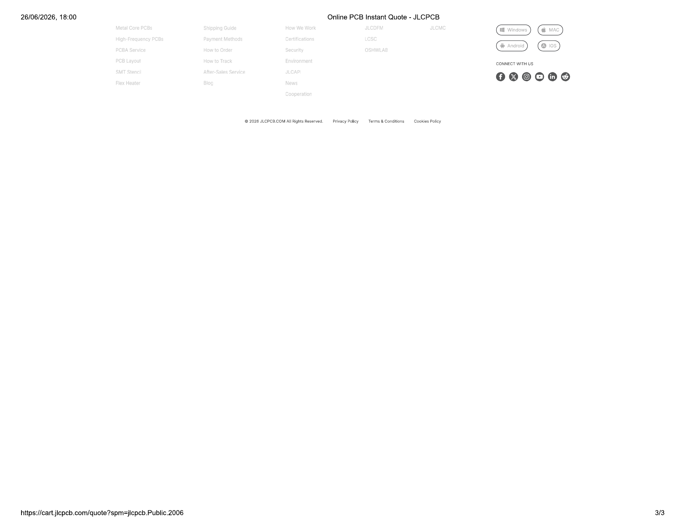
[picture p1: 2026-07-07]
tmp/pdfs/jlc/page-3.png

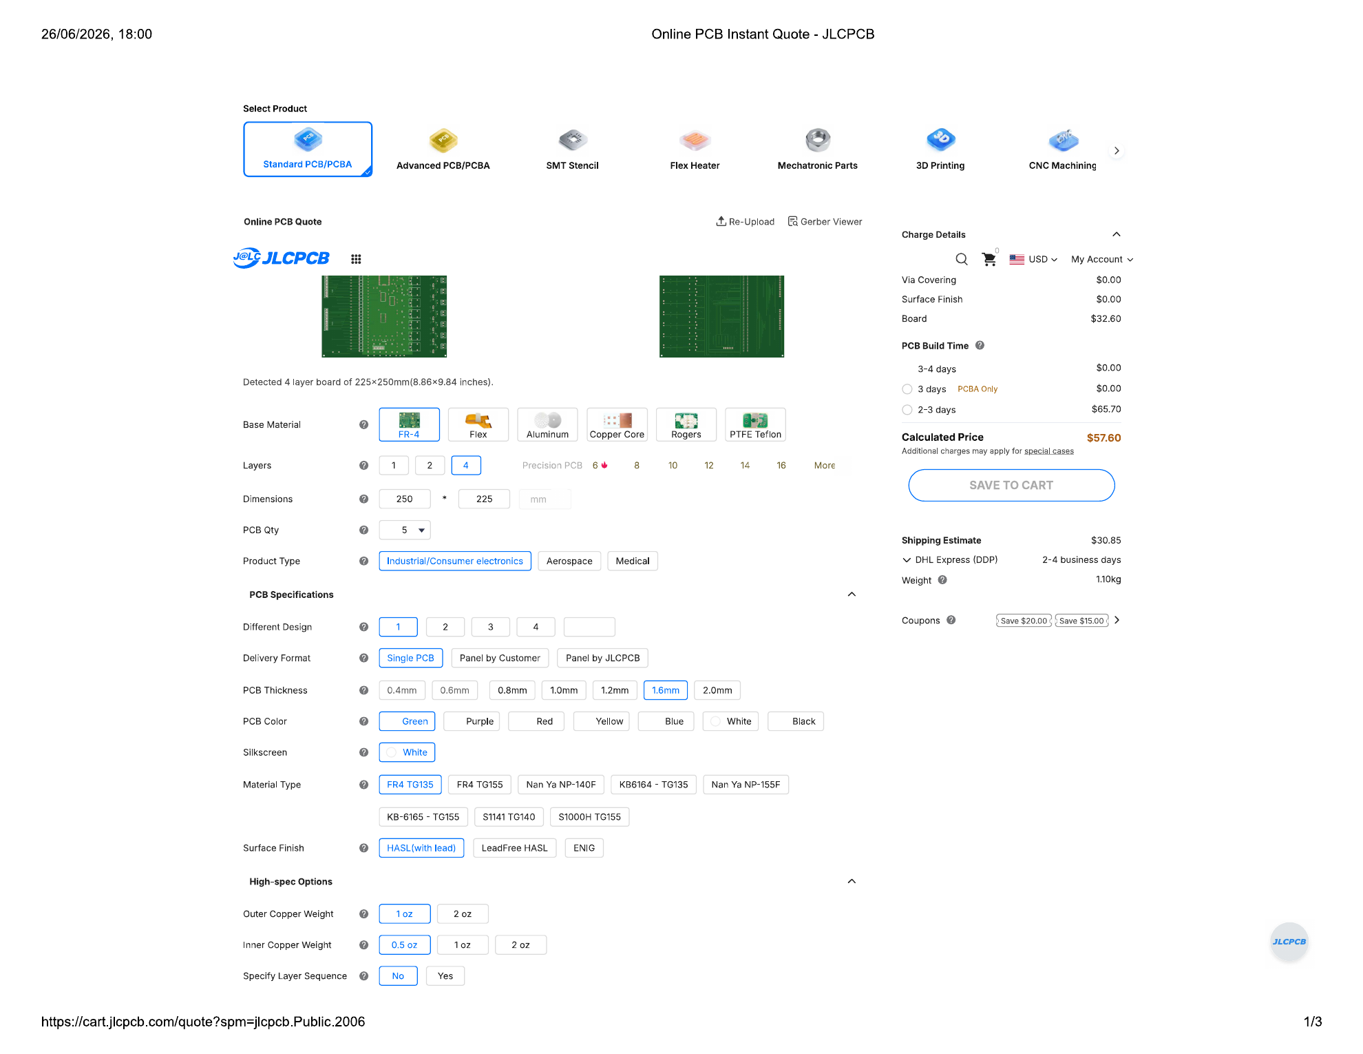
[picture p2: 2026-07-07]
tmp/pdfs/jlc/page-1.png

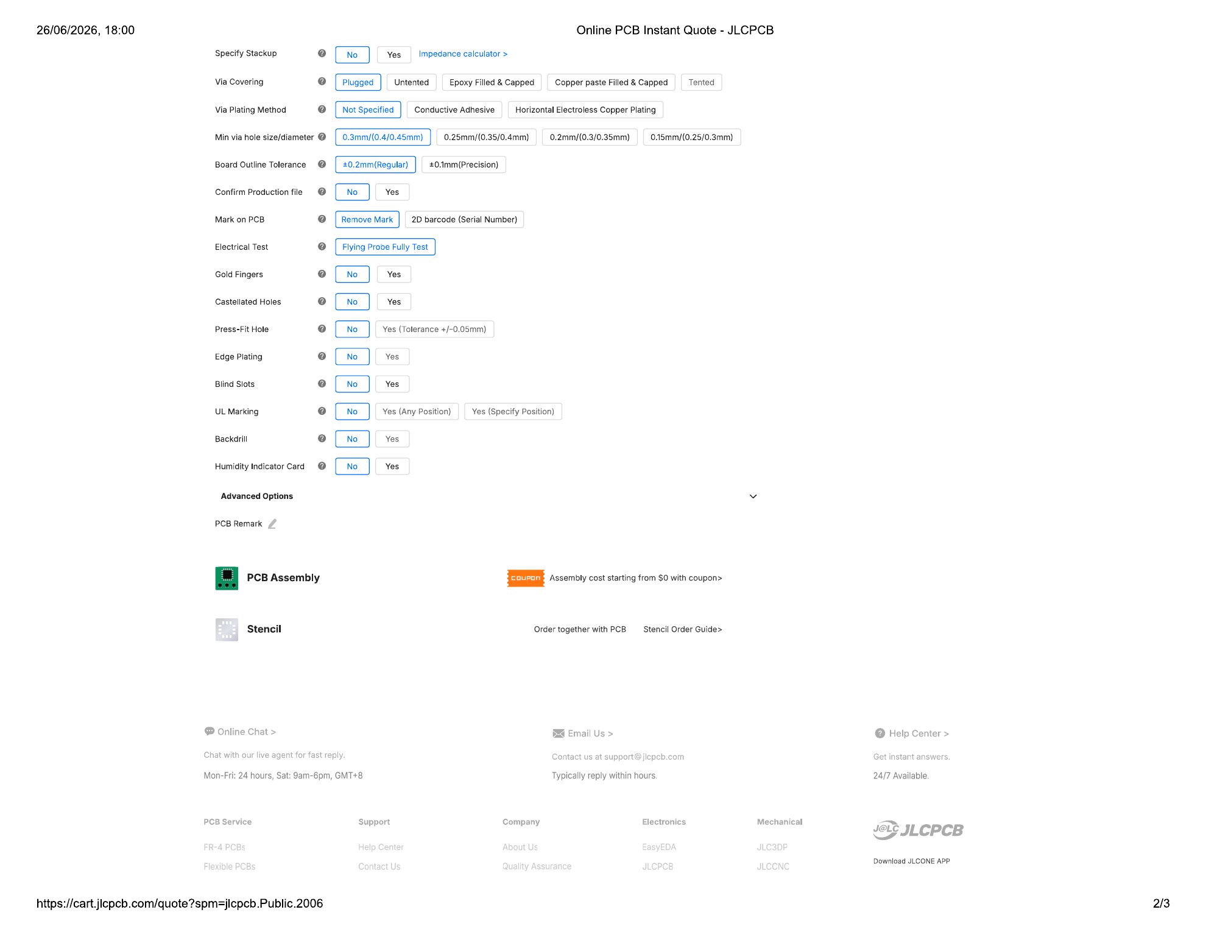
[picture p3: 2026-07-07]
tmp/pdfs/jlc/page-2.png

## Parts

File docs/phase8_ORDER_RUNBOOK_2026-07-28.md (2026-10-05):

# Phase 8 rev-D — ORDER RUNBOOK

**Written 2026-07-28. Supersedes the scattered decisions in `phase8_backplate_BOM.md`,
the pre-order audit, and the JLC correspondence notes.**
This is the single document to work from when placing orders.

---

# PART 1 — WHAT WAS DECIDED

## The five standing decisions

| # | Decision | Consequence |
|---|---|---|
| 1 | **ZERO HAND-SOLDER.** JLC places all 323 parts. | `kicad/fab_revD_2026-07-27_r10/` ships **as-is**. No r11, no re-cut, no re-verification. |
| 2 | **COST IS NOT A FACTOR.** Schedule and certainty win. | Global Sourcing is rejected on lead time despite being ~$380 cheaper. Consignment overage is bought freely. |
| 3 | **CONSIGN, DON'T GLOBAL-SOURCE.** | 13 lines bought at distributors and shipped to JLC. JLC still solders every one. |
| 4 | **FLEET = 34 BOARDS** (32 lanes + 2 spares). | Parts ordered at 38 sets (34 + 4 spare sets), then +25 % overage on consigned lines. |
| 5 | **Harness is the owner's to chase.** League delay accepted. | Board schedule is optimised independently. |

## Why Global Sourcing was rejected

JLC quoted (ref `XOB2026072800482-12616613A`, expires **Aug 13–24 GMT+8**):

| MPN | GS lead |
|---|---:|
| TMA 0505S | 7 bd · 1.4 wk |
| 1843680 | 8 bd · 1.6 wk |
| 1843703 | 21 bd · 4.2 wk |
| 3020-20-0100-00 | 21 bd · 4.2 wk |
| **1843729 (J4)** | **75 bd · 15 wk** |

⚠️ **The "4.2 wk" figure in older notes is the PARTS PROCUREMENT lead, not board-in-hand.**
It was mislabeled "Board lead" in `phase8_backplate_BOM.md:557`. There is no build term and no
freight term in it. Real board-in-hand on that route is **~6.4–8.8 weeks**.

Once *any* line is consigned, the consignment leg (~2–2.5 wk) is the critical path and JLC does
not start the build until every part is on hand. Splitting the two fast lines off to Global
Sourcing therefore buys **zero days** while adding a second process. Hence: consign everything
that isn't solidly in JLC's own stock.

**Estimated board-in-hand: ~4–6.5 weeks from upload.** Every step after "buy" is an estimate,
not a JLC commitment — see the questions in Part 2, Step 2.

## The three risks being accepted

1. **⚠️ N = 0 driven-24 VAC channels.** `readiness_checklist:124-134` — cams read as dry
   contacts is *"what lets 34 boards ship against the current revision"* and *"is reversible only
   by a board revision."* That decision was **delegated, not owner-measured**, and SA/SB/SC/TA1/
   TA2/TB are still recorded UNMEASURED. **One powered scope session at a cam microswitch settles
   it. A DMM cannot** — it can't separate 60 Hz AC from a chopped DC train.
2. **⚠️ PC817B CTR bin.** Design assumes **B rank, CTR 130–260 %**. No distributor page states
   the bin; LCSC prints `"600%;50%"` (the ungraded family span). The whole 22.3× → 16.4× margin
   stack rests on that floor, across 1,520 parts. **Mitigation: demand the bin on the CoC.**
3. **⚠️ r6 has never existed in copper.** Series `Dser` + anti-parallel `Dclamp` on all 40
   channels are paper-validated only. FA-16/FA-15/FA-9 are the proof and they run *after*
   delivery. **Mitigation: run the existing bench pre-check now** (`phase8_FA9_bench_precheck_guide.md`
   — ~1 h, zero new parts, and it is 4.7× harder than the real board).

## What is NOT a risk — checked and dismissed

- **2N7002 lamp drivers (Q8–Q11).** A stock-audit flagged the 115 mA rating as marginal.
  It isn't: `lamp_led_output()` fits a **330R limiter in every LED return**
  (`generate_kicad_netlist_revB.py:305,312` → R106/R109/R112/R115). Worst case 5 V/330R =
  **15 mA against 115 mA — 7.7× margin.** No respin question.

---

# PART 2 — THE JLC ORDER, STEP BY STEP

## STEP 0 — Close the pre-order gates ⛔ BLOCKING

`readiness_checklist:4` — *"Do not place a fab order until every PRE-ORDER GATE is `[x]`."*

| Gate | State | What closes it | Time |
|---|---|---|---|
| **G8** — 250×240 board growth sign-off | `[~]` | Dylan appends the sign-off line in `phase8_revD_run_log.md` gate **OG-1**. The evidence record is already there waiting. | **2 min** |
| **G7** — rev-C verify items 6–7 | `[~]` | **Either** the powered at-machine metering session, **or** Dylan records an explicit waiver in `phase8_revD_run_log.md` accepting rev-C-validated defaults for this spin. | 2 min (waiver) |
| **G13** — mating + coding parts ordered | `[ ]` | Place the §B plug + coding-profile order (Part 3, Group 2 & 3). Ships **with** the boards. | same day |
| **G12 Part A** | `[x]` | closed 2026-07-26 | — |
| **G12 Part B** | `[ ]` | **Cannot close before upload.** It is the checklist you run *at* the JLC preview screen — Step 6 below. | — |
| G16 | `[ ]` | ✅ **Not a fab blocker** — explicitly *"blocks LIVE, not fab."* | — |
| G17 open items | `[ ]` | ✅ **Not a fab blocker** — FA-16 / FA-15 / Record-N are first-article gates that need physical boards. | — |

> ⚠️ **If you waive G7 you are accepting one specific thing:** a 24 VAC cam channel is
> *survivable but not usable* under r6 — 60 Hz gives 12 debounced edges per 100 ms against
> `CHATTER_MAX_CAM = 8`, so it faults continuously. **Closing that needs a firmware change or
> tapping the cams at the switches — not a board change.** The boards are still correct.
> What a waiver does *not* cover is the `FIELD_WET_V` rail budget: **N ≥ 1 reopens it**
> (16.8 mA peak/channel, zero bulk capacitance). That one is board-level. Scope TP4.

## STEP 1 — Verify package integrity

```bash
cd "C:/Users/Dylan DeYoung/wsl-lane-nodes" && py -3 scripts/verify_fab_package.py kicad/fab_revD_2026-07-27_r10
```

*(Script written 2026-07-28 — verifies all 46 manifest hashes, the live board/netlist
hashes, the 391/68/323/323/37/0 counts, BOM↔CPL refdes equality, and the 0/0/0 DRC
report. Always `py -3`, never `python` — the bare `python` is the broken MS-Store stub.)*

Also re-verify the rev-C sacred snapshot (checklist G6's standing pre-order requirement):

```bash
cd "C:/Users/Dylan DeYoung/wsl-lane-nodes" && py -3 scripts/verify_revC_snapshot.py --compare-checkout
```

⚠️ **Re-verify `source_board_sha256` against `manifest.json` immediately before upload.**
`kicad/revD/~wsl-phase8b-revD.kicad_pro.lck` is stale and **any KiCad save silently breaks it.**

Expected: 391 parts · 68 DNP · 323 placed · 323 JLC · 37 lines · **0 hand-solder** · DRC 0/0/0.

## STEP 2 — Ask JLC the open questions (send today, free)

Three quote lines lapse **Aug 13 GMT+8**, so there is time for one round trip.

> On quote `XOB2026072800482-12616613A`:
>
> 1. Is the quoted per-line lead time the date the **parts arrive at your factory**, or the
>    date the **finished assembled boards ship** to us?
> 2. If it is the parts date — what is the additional PCB fabrication + PCBA build time after
>    the last line lands, for **34 pcs of a 250 × 240 mm board with 323 placements** including
>    wave-soldered through-hole?
> 3. Do you begin the SMT pass on library-stock parts while a consigned or Global Sourcing line
>    is still inbound, or is the whole job held for a complete kit?
> 4. **Through-hole capacity:** this order carries **≈9,900 through-hole joints across the
>    34 boards** — 1,360 × PC817B DIP-4, 204 × G5LE-14 relays, 476 × Phoenix terminal
>    blocks (14 bodies / 77 pins per board), 34 × 2×10 IDC, 34 × SIP DC/DC. Can you confirm
>    in writing that wave/THT capacity is available for this quantity, and what it adds to
>    the build time? *(figures corrected 2026-07-28 to the 34-board placement counts — the
>    old text mixed in 38-set purchase quantities)*
> 5. For a **consigned** part, how many days between receiving our parcel and starting the
>    build (receiving, counting, incoming inspection)?
> 6. What is the earliest **ship date** you can commit to if we order this week, and what
>    expedited shipping options exist?

⚠️ **Question 4 is the important one.** Going zero-hand-solder moved every one of those joints
onto JLC. THT runs a separate, surcharged, capacity-limited path — it is a bigger schedule
threat than any stock line in this document.

## STEP 3 — Read the TRUE stock (⭐ the highest-value 60 seconds in this runbook)

Roughly **half of the ~24 lines JLC would supply** (37 upload lines − 13 consigned) have
unreadable stock — `jlcpcb.com/partdetail/<C#>` injects the number via JavaScript, so it can't
be read externally. LCSC's retail pool is a **different pool** and disagreed by ~2× on three lines.

1. Log in to JLC → **SMT Assembly quote → BOM upload / parts-matching**
2. Upload `assembly/wsl-phase8b-revD-jlc-standard-pcba-upload-bom.csv`, keyed on **C-number,
   never MPN**
3. That screen prints live assembly stock + an insufficient-stock flag for every line at once
4. **Screenshot it.** Pay closest attention to:
   `C17513` (1k) · `C116963` (relay) · `C5692981` (PC817B) · `C5443576` (Phoenix 6-pos) ·
   `C47023` (MCP23017) · `C17520` (2.2k) · `C89827` (10 µF) · `C17702767` (10 nF) ·
   `C2933281` (10M) · `C17713` (47k — 40/bd, one of only three 1,500-piece-scale lines) ·
   `C118873` (1N4148WS — 88/bd, the largest line in the build)

⚠️ **"My Part Lib" is a bookmark, not an allocation. Nothing is reserved until the order is
placed AND paid.**

## STEP 4 — Finalise the consignment list, then buy

Part 3, Group 1 is the list as it stands from external data. **Step 3's screen is authoritative** —
add or remove lines from it. Buy everything with **+25 % overage**.

> ✅ **STEP 3 EXECUTED 2026-07-29** — matching export archived at
> `docs/phase8_jlc_bom_matching_2026-07-29.xlsx` (JLC download 10:34, qty-50 basis).
> **37/37 lines matched by C-number, zero warnings, part-lock held.** Result:
> - **CONSIGN (6 lines, stock 0/short):** 1843680 (0) · 1843729 (0) · 1843703 (3) ·
>   3020-20-0100-00 (0) · **TMA 0505S (16 — consign ALL, no-mixing rule)** · 10 µF C89827 (1).
>   Buy at the Group 1 quantities: 95 / 48 / 48 / 48 / 48 / 200.
> - **DROP from consign (JLC covered the full need):** C5443576 **100 ✓ → stays a JLC line,
>   Group 1 row 13 is DEAD** (keep it in the no-sub remark) · C116963 relay 300 ✓ ·
>   C47023 150 ✓ · C17513 610 ✓ · C2933281 160 ✓ · C880333 50 ✓ · C17702767 56 ✓ ·
>   Pico 50 ✓ · C118873 4,406 ✓ · C17713 2,010 ✓.
> - **PC817B C5692981: 2,003 ✓ — DECISION (Dylan):** JLC can supply the whole build.
>   Consigning never resolved the B-bin question (no distributor states it either).
>   Recommended: JLC-supply, drop the 1,900-pc consign buy, enforce B-rank via the remark +
>   reel-label check at incoming + FA-9. Consign only for chain-of-custody.
> - ⚠️ Covered = allocated-at-match, not pool depth. **Re-match if >24 h pass before payment.**
> - ⚠️ The 2026-07-29 session ran at qty 50 — re-quote at **34** before paying.

> ✅ **2026-07-29 FINAL ORDER DECISIONS (supersede the two lines above where they conflict):**
> - **QTY = 50 assembled boards** (Dylan — JLC custom-qty constraint; 16 assembled spares
>   beyond the G15 fleet 34. Note next to the OG-1 signature in the run log).
> - **PC817B = JLC-SUPPLIED.** The 1,900-pc consign buy is DEAD. Enforcement = B-rank/CoC
>   demand in the PCBA remark + reel-label check at incoming (Step 8) + FA-9 per channel.
> - **Consignment = exactly 6 lines**, scaled to 50 boards +25 %:
>   **1843680 ×125 (Mouser)** · **1843729 ×65 (DK)** · **1843703 ×65** ·
>   **3020-20-0100-00 ×65** · **TMA 0505S ×65** (consign ALL — no-mixing rule; JLC's 16
>   are unusable alongside ours) · **10 µF C89827 ×200**. Confirm JLC's attrition
>   requirement per line BEFORE the parcel ships (consignment runbook §3.3).
> - **J14 plug 1840382 = 72** (the harness BOM's +1-spare-per-lane rule stands; Group 2 note closed).
> - **G10 camera entry = TWO M20 glands per pair, one per coax** (passes a moulded RCA,
>   seals on the cable, zero field termination). **E7 becomes 96 (+12) M20 + 80 (+10) M16.**
> - **Lead-time strategy — ANSWERED by JLC chat 2026-07-29 (Mitchell Chen):** ⛔ **NO
>   pay-now.** *"We do not support such process to produce the PCB firstly … wait until the
>   part in stock then to place the PCBA order later."* The consignment parcel IS the
>   critical path; fab starts only after receiving. Consequences: buy + ship the 6 lines
>   IMMEDIATELY; **re-match the BOM at payment** — the tight covered lines (C880333 = 50
>   exact · C47023 = 150 · C2933281 = 160) are unprotected during the ~2-wk wait; if one
>   drains, buy it at a distributor same-day and send a small second consignment parcel.
>   Consignment declarations submitted 2026-07-29 (6 lines; TRACO matched C5454708 — no
>   email-approval gate; attrition shown in-UI: 0 on all THT lines, min-20+6 on C89827).
> - Production-file approval rule: accept 250×240 (no rails) or **260×240** (left/right
>   rails); **REJECT 250×250** (top/bottom rails — component damage at U45/U43/row-39).

## STEP 5 — Open the consignment flow

Follow `phase8_jlc_consignment_runbook.md` — **§3–§5 flow mechanics ONLY.** Its §1 decision
gates (GS-first) and §2 quantity table (5 lines at 72/38/38/38/38) are SUPERSEDED by Part 1
decisions 2–3 and the Group 1 table above. A literal follower of that doc buys 5 lines at the
old quantities and under-declares 8 lines — JLC then can't kit the build.
⭐ Also: its "TRACO has no JLC library entry" premise is stale — **C5454708 exists.** Try
matching it in Parts Manager first; only fall back to the direct-consign/email-approval path
if it doesn't match. That skips the review round-trip the doc plans its schedule around.

Get from JLC: the consignment order number, the receiving address, the parcel labeling
requirement, and the fee schedule (visible in-flow).

⚠️ `phase8_jlc_consignment_runbook.md:117` — *"Confirm they appear before releasing the board
order."* **Ask whether that blocks *placing* the order or only *releasing* it to the line.**
It is worth 1.5–2.5 weeks either way.

⚠️ **JLC disclaims quality liability on consigned stock.** That is what the overage is for.

> 🔄 **2026-07-30 SHIPMENT STATE:** declaration WBG2026073100878 submitted, 6/6 lines
> "Reviewing". **SHIP-TO CHANGED — Hong Kong, NOT Zhuhai:** Rebecca (12616613A),
> +852 5421 0550, Block 1 Room 3B, 3 Hung Cheung Road, Tuen Mun, New Territories, Hong Kong
> (banner: "shipping address and customs prepayment rules have changed"). Photograph EVERY
> bag label (PN + COO) before sealing — stated requirement. Combined invoice PDF =
> `Downloads/JLC_consignment_invoices_DK129986470_Mouser91667952.pdf`.
> ✅ **CLAUSE 1 RESOLVED — governed by Dorae's LOGGED 2026-07-27 written reply** (not a fresh
> chat answer; a re-confirmation sat unanswered in chat 2026-07-30 and is NOT a ship blocker):
> the rule is SAME-part source mixing only — "for different parts, you can use JLC parts for
> part A and consigned parts for part B." Our 24-JLC + 6-consigned structure is VALID.
> Residual worst case surfaces at the order screen BEFORE payment (flip the 24 JLC lines to
> Global Sourcing); the 6 consigned lines are needed under any structure → parcel risk zero. ✅ TMA date code verified
> on the cans: **1023 (Oct 2023)** — the packlist's "Jun-2010" was a data artifact; clause-5
> concern closed. **PARCEL CLEARED TO SHIP** (photos of all 6 bag labels kept in a folder
> named WBG2026073100878 — produced only if JLC/customs asks).
> ⚠️ Still open, unrelated to the box: DigiKey code-89 decline ($6,394.99) — deadline
> ~Jul 31 10 PM.
> ✅ **2026-08-01:** PUSHED to origin (994ce79..1452985). **OG-1/G8 + G7 SIGNED** — all fab
> gates closed. DigiKey code-89 RESOLVED. ORDERED: DK add-on (M3DDA-2006J ×50 secured + fans
> + vents + patches + loom + mounts/ties + ribbon 25 ft + grey/violet/brown stranded) ·
> **Calrad 55-877-20 ×36** · **Siemon Z-PLUG + Z-TOOL**. Amazon remainder still open, NOW
> +**1,000 ft Cat6 (attic runs to the overhead displays — forgotten scope**; CMR/riser
> jacket for attic; check Z-plug count + PoE/switch PORT count cover the display drops too).
> Still homeless: VC500 ×1 · uxcell pigtails ×20 · Aim Dynamics glands (status unconfirmed) ·
> Zoro brass · pink spool · 1 MΩ 1 W ×25.
> ⚠️ **2026-08-07 — PACKING ERROR, contained:** JLC HK found TWO undeclared bags in the
> parcel: **1840463 ×40** (Mouser, J5 field plug, $561) and **1840405 ×76** (DK, J13/J16
> plug, $434) — the keep-at-home free-issue stock, boxed by mistake. Caught in HK BEFORE
> mainland customs → no declaration issue (the 6 declared lines match the invoice exactly).
> Asked Lyvia: process the 6 lines without delay; hold the 2 stray bags as customer property
> and return them WITH the PCBA order shipment (fallback: SF return at our cost). Impact
> ~zero: MiniProto self-sources J5/J13 (our stock was fallback only; both PNs re-buyable),
> J16 plugs not needed until commissioning ≈ board-arrival time. Home stock ledger until
> return: 1840447 ×76 · 1840489 ×50 (inbound) · 1840382 ×72 · coding stars ×30 — **J5/J13/J16
> plug stock is ZERO at home.**
> ⛔ **2026-10-05 — SECOND REJECTION: JLC's "most recent" photo is the SAME STATE as Sep 16.**
> Full-board top-side photo read against the r10 CPL (photo rotated 90°, ~7.7 px/mm) by me and
> three independent readers (coordinate lens / silkscreen lens / adversarial lens): **unanimous
> ALL SIX CONSIGNED POSITIONS BARE** — J1 (20 open holes, no shroud), J3/J4/J5/J15 (10/14/12/10
> open holes under their upside-down labels), U45 (4 open SIP holes, no block), C14 (two bare
> 0805 pads, waived). Every JLC-sourced line present and correctly oriented: K1–K6 uniform,
> 40/40 PC817, U1–U3 pin-1 consistent, C11 stripe opposite the "+", Pico USB to the board top
> edge, J2/J6–J11/J13/J14/J16/U44/U46/U47 fitted; no solder defect at this resolution. Every
> other bare footprint = the 68 designed DNPs exactly (40 Cflt, 7×3 snubber, K7/J12/Q7 + M1
> driver parts, JP1). **Nothing requested on Sep 21 is visible; 14 days lost.** Rejected again,
> this time with escalation (Lorraine CC) demanding: is this a pre-rework photo re-attached or
> has the rework not happened; written confirmation the five THT consigned lines are in the
> production BOM with the library deduction visible (125/65/65/65/65 → 25/15/15/15/15 after 50);
> a named owner + rework date; a post-rework photo, both sides, before any shipment. Boards now
> late October at best. **Do NOT approve any photo without the headers, J1 and U45 in frame.**
> 🔄 **2026-09-21 — HARNESS: review page edited to 34/18 + Standard ($12,832); NOT approved.**
> Quantities and tier verified correct (RFQ program, price breaks, board slip). Approval gated on
> Alex's written answers — expiry, NRE/labels = $0 add-on, FA flow under Standard, Rev 4/Rev 2 on
> the PO record, payment path + ship-to, J5/J13 stock. Full detail in Group 8 G1. Free-issue
> 1840489 ×40 ships after the acknowledgment. Standing decision #2 superseded for this line.
> 🔄 **2026-09-21 — JLC ASKS WHETHER TO USE THE CONSIGNED PARTS (answer: YES, all six, all 50).**
> JLC's reply to the rejection confirms the cause: production never pulled the consigned
> library, and asked "do you need us to take the following parts from your consigned parts
> lib?" — with a **garbled mapping** (C3582595 "on J5", C3019636 "on J15", J4 absent). True
> mapping per the uploaded BOM/CPL: C3585531 (10-pos) → J3+J15 · **C3582595 (14-pos) → J4** ·
> **C3019636 (12-pos) → J5** · C17373551 → J1 · C5454708 → U45 · C89827 → C14. Replied with the
> corrected table + orientation notes, citing WBG2026073100878 / Aug-22 check-in / pre-payment
> "Consigned Parts" matching. **C14 (C89827, 10 µF 0805) CANNOT be added — SMT stage closed.**
> Netlist: C14 = `C_3V3_BULK`, the only 10 µF on VCC_3V3 (fed from the Pi header J1; the rail
> keeps C1/C2/C3/C16 100 nF locals + the Pi's regulator caps) → board functions without it,
> loses header-transient margin. **Disposition: proceed without C14, do NOT hold the order**;
> JLC may hand-fit it only if it costs no lead time; **all 200 pcs C89827 + the unused balance
> of the other five lines returned to us** (with the boards if allowed, else in the SF return
> with the two stray bags). **C14 becomes a 50-joint hand-fit at incoming inspection (Step 8)
> — the one exception to standing decision #1; ~1 h total, 0805 with tweezers.** Gate still
> open: NEW assembled-board photo, both sides, J1/J3/J4/J5/J15/U45 visible → approve → DHL.
> ⛔ **2026-09-16 (later) — FIRST ARTICLE BUILT WITHOUT THE CONSIGNED PARTS.** A real
> assembled-board photo surfaced: every JLC-sourced line populated and correctly oriented
> (relays, optos, 3× MCP23017, J2/J6–J11/J13/J14/J16, Pico USB-to-edge with silkscreen) —
> but **J3/J4/J5/J15 (consigned Phoenix headers) are BARE**; J1/U45/C14 (also consigned)
> presumed missing pending a hi-res look. Likely cause: the six consigned lines never
> entered the production BOM (exports only ever listed 31 JLC lines; the preview's bare
> outlines were consistent with either). Rejected via "No, doesn't match" with a demand to
> install all six consigned lines on all 50 boards from consigned stock + new photo; asked
> whether the lines were in the production BOM + stock balances. Owner to check the order's
> BOM tab. Possible J12 (M1 DNP) populated — harmless, noted. Fallback (NOT the plan):
> ship + return parts, hand-solder ~30 h, breaks decision #1.
> ⛔ **2026-09-16 — PHOTO CONFIRMATION WITHHELD:** JLC's "Photo Confirmation before Shipment"
> attached photos of a BARE, UNPOPULATED board (our board, rotated 90° — no relays, headers,
> optos or Pico; featureless bottom). Cannot verify the first-article gates from it. Answered
> via the "No" path with a request for assembled-board photos both sides (Pico silkscreen +
> USB orientation, U4–U43 orientation, consigned J3/J4/J5/J15 + U45 soldered, K1–K6).
> Do NOT approve until the assembled board is in frame.
> ✅ **2026-09-02 — PLACEMENT CONFIRMATION (THT polarity/orientation) VERIFIED:** JLC's 3D
> preview cross-checked against a fresh `kicad-cli pcb render` of the r10 board — J6–J11
> MKDS wire entry outward at the right edge, J2 outward at the top edge, J13/J16/J14 MCV
> vertical headers, K1–K6 uniform (rotations identical to the rev-B JLC CPL) — all match
> design intent. Confirmed to Rosy with the consigned-part orientation notes (J1 key, U45
> SIP pin 1, J3/J4/J5/J15 pin 1, A1 USB toward top edge — all per silkscreen). Last gate:
> first-article photo.
> ✅ **2026-08-26 — REVISED PRODUCTION FILE VERIFIED AND APPROVED:** parse-proven panel
> **260.00×240.00**, board X 5–255 / Y 0–240 (884/884 drill fit), rails LEFT+RIGHT 5 mm,
> **vertical** V-cuts at X=5/255 (8–9 mm from nearest parts), board top/bottom edges free of
> internal scoring (Y=0/240 marks = mother-array boundary, separated at bare-board stage),
> source gerbers 16/16 identical to r10. Production released. Remaining gates: first-article
> photo (Pico silkscreen, opto uniformity) → ship.
> ⛔ **2026-08-25 — PRODUCTION FILE Y5 REJECTED (the tripwire fired for real):** despite the
> approved left/right EQ, the Y5 CAM shipped **250×250 with rails TOP/BOTTOM and horizontal
> V-cuts at Y=5/Y=245** — scored edges 0.52 mm from U45 / 0.63 mm from U43. Proven by parse:
> 884/884 drill match at rotation 0, board at panel Y 5–245 full-width. Source gerbers inside
> Y5 = byte-identical to r10 (16/16) — design untouched, panelization alone wrong. Rejection
> sent citing the Aug-24 approved render; required: ≈260×240, vertical V-cuts, top/bottom
> edges free of scoring. **Do not confirm any production file without re-running this parse.**
> ✅ **2026-08-24 — RAIL TRIPWIRE DISARMED** *(premature — see above)*: JLC engineering (swee@) quoted the remark back
> and proposed **LEFT/RIGHT rails** with a render showing exactly the pre-approved geometry
> — approved same day with the no-top/bottom prohibition restated + depanel-before-delivery
> reconfirmed. The remark mechanism worked as designed. Remaining watch: placement
> confirmation + first-article photo (Pico silkscreen, opto uniformity).
> 🎉 **2026-08-23 — PCB + PCBA ORDER PAID (~$4,100).** 50 boards, all 37 lines sourced
> (31 JLC + 6 consigned), full-quantity requirement, ENIG, fully e-tested. **POST-PAYMENT
> WATCH: (1) production-file approval — accept 250×240 or ~260×240, REJECT 250×250 (the
> order metadata still reads 250×250 = the system's top/bottom rail default; the remark +
> this gate are the control); (2) placement confirmation (F1 −90°/U46 0°/U47 180°/Q17–Q20
> 180°, optos uniform); (3) first-article photo (Pico silkscreen).** Boards ≈ mid-Sept.
> ⚠️ HARNESS PO: funding gap — MiniProto quote **expires Aug 26**; extension request or
> staged PO (FA + pilot now, balance later) must move before then.
> ✅ **2026-08-23 (later) — SHORTFALLS CLEARED WITHOUT ACTION:** re-match shows 1N4148WS
> 4,406/4,406 and G5LE-14 300/300 (JLC replenished from LCSC); all 31 JLC lines + 6 consigned
> covered. **CLEARED TO PAY — same session, before the pool moves again.**
> ⚠️ **2026-08-23 — TWO JLC LINES DRAINED during the 3.5-week wait:** C118873 1N4148WS
> 3,815 vs 4,406 (**591 short**) · C116963 G5LE-14 205 vs 300 (**95 short**) — the relay is
> the line we DROPPED from consignment when it read covered. Fix = **Parts Manager → Order
> Parts into personal inventory** (LCSC transfer, 1–3 days, no customs, legally combines
> with the public pool): C118873 ×700 · C116963 ×105 (exact G5LE-14 5VDC, no -CF/-ASI) +
> thin-line buffers C880333 ×10, C13612 ×10 (both pools exactly at need). ⛔ NOT a
> substitution, NOT a consign-delta (same-part mixing forbidden). Re-match after stock-in,
> then G12-B → pay. If C116963 unavailable at pre-order: fallback = GS that line (legal
> beside consigned), then consign-all as last resort.
> ✅ **2026-08-22 — ALL SIX CONSIGNED LINES CHECKED IN** (My Parts Lib: 65/65/65/125/65/200
> — exactly as declared). Package re-verified same day: 46/46 hashes, live board match,
> DRC 0/0/0. **BOARD ORDER UNBLOCKED — proceed to Step 6: match (6 lines from Consigned
> Parts; re-check C880333/C47023/C2933281), G12-B preview, PAY.** Then: production-file
> approval (reject 250×250) + first-article photo (Pico silkscreen).
> 🔄 **2026-08-19 — stray-bag return in motion:** JLC cannot ride-along loose parts with the
> PCBA shipment (Jax). Return via SF Express, receiver pays; details + HS codes + invoices
> sent to Lyvia (1840463→8536.69.4040, 1840405→8536.90.4000, re-import as HTS 9801.00.10
> returned goods, ~$995 value vs ~$50-100 freight). ⚠️ Six declared lines STILL not
> confirmed received as of Aug 19 (delivered Aug 5!) — confirmation requested in the same
> email; **escalate to Lorraine (lorraine@jlcpcb.com) with the FedEx POD if not resolved
> within ~2 business days — the PCBA order is blocked on this.**
> 📦 **2026-07-31:** parcel SHIPPED — FedEx **875182889683** to the Tuen Mun address; JLC
> declaration still "Reviewing" so tracking not yet attachable (ping if not cleared by
> ~Aug 3). AD + DK main + Mouser orders ARRIVED. Amazon/GPT basket + DK add-on
> (⚠️ M3DDA-2006J is vanishing EOL stock) + VC500 sample + Siemon Z-PLUG+Z-TOOL (verify
> solid-23AWG variant) NOT yet ordered. Plywood: cut+prime today, DRILLING gated on the
> F-1019 caliper (CZH inbound). Harness shop quiet on Rev 2 (nudge Mon; quote to Aug 26).

## STEP 6 — Place the PCB + PCBA order

**Files:**
- PCB → `wsl-phase8b-revD-gerber-drill.zip`
- PCBA BOM → `assembly/wsl-phase8b-revD-jlc-standard-pcba-upload-bom.csv`
- PCBA CPL → `assembly/wsl-phase8b-revD-jlc-standard-pcba-cpl.csv`

⚠️ **CPL filename corrected 2026-07-28** — there is NO `…-upload-cpl.csv` in the package.
⛔ **Do NOT grab `wsl-phase8b-revD-cpl.csv`** (the similarly-named file next to it) — that is
the raw KiCad export in a different column format. The JLC one is the
`…-jlc-standard-pcba-cpl.csv` with `Designator / Mid X / Mid Y / Layer / Rotation` headers.

**Service tier:** ⚠️ **Standard PCBA, not Economic.** `C7203002` (Pico) is the only line flagged
*"Standard Only"* — **that single part forces the whole order onto Standard.** Confirm it's priced
that way.

**Paste into the PCBA remark, verbatim:**

> Board is 250 × 240 mm. No process rails should be required. If any process rail IS added, it
> must be on the LEFT or RIGHT edge ONLY — never the top or bottom edge. Components sit within
> 5 mm of the top and bottom edges (nearest 0.52 mm at U45, 0.63 mm at U43) and depanelisation
> there would damage them. A left/right rail changes the outline; this is pre-approved.
>
> NO SUBSTITUTIONS on: C8678, C16338, C5692981, C47023, C880333, C13612, C207035,
> C116963 (Omron G5LE-14 5VDC — exact coil voltage, no -CF/-ASI suffix), and every Phoenix
> line on this order whether JLC-supplied or consigned (C480520, C480516, C5443576, C480549,
> C3585531, C3582595, C3019636). C19184134 must ship as the RS-branded part, NOT
> Fujicon C18214278. C5692981 PC817B must be **B rank (CTR 130–260 %)** with the bin stated on
> the CoC / reel label.

⚠️ JLC confirmed 2026-07-27 they follow rail instructions **only if written in the PCBA remark.**
They did *not* confirm rails are unnecessary.

**G12 Part B — run this at the preview screen, before paying:**

- `[ ]` Preview reads **250 × 240 mm** (rev-D is 240 tall, not rev-C's 225)
- `[ ]` **Part rotation** on the four classes new in rev-D — `F1` (1206L020YR), `U46` (TCA4307
  VSSOP-8), `U47` (SRV05-4 SOT-23-6), `Q17–Q20` (2N7002LT1G). The CPL ships raw KiCad rotations
  and the exporter has **no rotation-correction table**.
- `[ ]` **A1 silkscreen photo** — confirm the Pico is the bare RP2040 module. ⚠️ **Do not quote
  "SC0915" to JLC** — their page lists the MFR part as "Raspberry Pi Pico" and nothing links that
  string to `C7203002`. *(JLC did confirm SC0915 in writing on 2026-07-27; pin the order to the
  C-number regardless.)*
- `[ ]` USB keep-out clear; row-39 bottom-edge copper (1.28 mm) acknowledged on **both** edges
- `[ ]` `C2933281` (10M) matched and in stock at the moment of upload
- `[ ]` `source_board_sha256` re-verified (Step 1)
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

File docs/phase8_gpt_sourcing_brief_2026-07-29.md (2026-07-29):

# GPT sourcing briefs — 2026-07-29 (capture device + remaining Amazon-class parts)

Written for hand-off to GPT. Two independent briefs. Both: US-stock sellers only,
delivery ≤ 2 weeks, prefer one seller per line, links required.

---

## BRIEF 1 — USB composite-video capture device, Linux-proven, ×18

**Context.** 18 Raspberry Pi 4 Model B nodes each need to capture analog composite video
(NTSC, yellow RCA, from a bowling T-Camera) over USB. Single still frames are the workload
(scoring uses stills; latency and audio are irrelevant; 720×480 is plenty). A VIXLW-brand
unit (~$46) worked, but it was only ever tested on **Windows** — its Linux behavior is
unknown, and cheap capture sticks routinely ship Windows-only chipsets.

**Hard requirements — a candidate fails unless ALL are met:**
1. Composite (CVBS) NTSC input via RCA; USB 2.0 output.
2. Works on **Raspberry Pi OS (Debian Bookworm, 64-bit) out of the box**: enumerates as a
   V4L2 device (`/dev/video0`) with NO vendor driver install. That means either
   (a) a true **UVC-class** device, or (b) a chipset with a **mainline Linux kernel
   driver** — known-good chipsets: **UTV007 (`usbtv` driver)**, **STK1160**, **CX231xx**.
3. Purchasable today: **18+ units** from one US seller (Amazon/B&H/etc.), ≤ $50/unit
   (prefer ≤ $20).

**Evidence bar.** For each candidate, cite at least TWO independent sources showing Linux /
Raspberry Pi use (forum thread, review, Reddit, blog, `lsusb` output naming the chipset) —
OR a listing that names the chipset outright. "Plug and play" in an Amazon listing is NOT
evidence; those claims usually mean Windows.

**Deliverable.** 2–3 ranked candidates: listing URL, price, stock signal, chipset (with the
evidence quoted/linked), and any known NTSC quirks. We will still bench-test ONE unit on a
Pi before buying the fleet quantity — rank by probability of passing that test.

---

## BRIEF 2 — remaining parts, exact specs (find one US listing each, qty in bold)

| # | Item | Spec — every clause is an acceptance criterion |
|---|---|---|
| 1 | USB-C power pigtail ×**18** | USB-C male plug → 2-wire bare/tinned open end (we crimp our own ferrules). Length **450–700 mm** (600 ideal; up to 1 m ONLY if ≥ 20 AWG). Conductors **≥ 20 AWG preferred** (24 AWG acceptable only ≤ 600 mm). 5 V / 3 A rated. Power-only is fine — no data, no e-marker. Powers a Raspberry Pi 4B from a DIN-rail 5 V supply. |
| 2 | Composite video cable ×**36** | Single RCA male–male, **75 Ω video coax** (RG59 or mini-RG59 construction — NOT thin "A/V audio" cable), **20 ft** (16–20 ft acceptable), moulded plugs. One seller must hold 36+. |
| 3 | Cable glands ×**108 M20** + ×**90 M16** | Nylon PA66, **IP68**, dome nut, WITH locknuts + sealing O-rings. M20 clamp range ~6–12 mm; M16 ~4–8 mm. Black or grey. |
| 4 | Fans ×**18** | **40 × 40 × 10 mm, 5 VDC, BALL bearing** (not sleeve), ~0.5–1 W, 2-wire, continuous duty. Quiet preferred. |
| 5 | Breather plugs ×**16** | **M12 Gore-type membrane vent plug**, nylon, IP67+, with locknut. |
| 6 | Cat6 patch ×**18** | ~**0.5 m** (0.3–0.6 m), snagless boot, stranded OK (in-enclosure patch, splitter → Pi). |
| 7 | Split loom ×**~136 m** | **10 mm (3/8") ID**, slit polyethylene loom. Bulk spools fine. |
| 8 | Adhesive tie mounts ×**400** + cable ties ×**500** | Mounts ~19–28 mm square, adhesive-backed, screw-hole preferred; ties 4 in nylon. |
| 9 | ESD bleed studs ×**16** | M4 brass stud/bolt + nut hardware, PLUS ×20 **1 MΩ 1 W** axial resistors (metal film fine). (Assembled on site — just find the two components.) |
| 10 | Hook-up wire, UL1007 **22 AWG** | Spools (≥100 ft each) in **VIOLET, GREY, BROWN, PINK** — these exact colors are a wiring-code requirement (isolated-sensor pair and camera pair). Remington Industries (Amazon) is known to carry all UL1007 colors — confirm current listings. Add black/red/white if cheap. |

**Out of scope** (already ordered elsewhere): DIN rail, duct, terminal blocks, fuses,
sensors, reflectors, M12 cordsets, ferrules, 18 AWG wire, SD cards, IDC ribbon, heatsinks.

---

# RESULTS — GPT audit returned 2026-07-29, dispositioned same day

**Capture:** DO NOT fleet-order yet. Sample = **Diamond VC500 (non-SE, NOT VC500SE)** ~$39.99
— historically Geniatech OTG102 (1f4d:0102) on mainline `cx231xx`, revision-sensitive; Amazon/FBA
exposes qty ≥30. Runners-up: AVerMedia C039 (07ca:c039, cx231xx — strongest driver evidence,
over $50/OOS) · TR Video-2-Pi (UVC, exact Pi still-frame evidence, no US qty). REJECTED: VIXLW
(Windows-only evidence), generic EasyCAP (chipset roulette), current Hauppauge USB-Live2
(revision drift), Sabrent AVCPT (discontinued). **Acceptance = GPT's script:** clean Bookworm
64-bit, driver must resolve to uvcvideo/cx231xx/usbtv/stk1160, NTSC 720×480 still, **100
open/capture/close cycles** (no black/green/stale frames), dmesg clean of URB/reset/timeout,
**5 cold boots**, then the seller same-revision/VID:PID letter BEFORE the 17-unit follow-on.
If the $11 clone test unit arrives, test it with the same script — first pass wins.

**Brief-2 picks (GPT):** uxcell USB-C 22 AWG 0.5 m ×20 (RELEASE — with the undervolt gate AND
the DDR-60G-5 output-trim mitigation: set rail ~5.15–5.2 V at commissioning, watch
`vcgencmd get_throttled` on the first pair) · Calrad **55-877-20** RCA/RG59 20 ft ×36 (HOLD:
36-qty confirmation from Calrad) · Beisit **M2012B ×108 + M1608B ×90** + locknuts via Aim
Dynamics (**PA66 hold WAIVED by Claude 2026-07-29** — indoor duty, any PA at IP68 acceptable;
ORDER) · Qualtek **FAD1-04010BBMW11** ×20 (Mouser) · Amphenol LTW **VENT-PS1YBK-N8001** ×16
(Mouser, ePTFE M12) · QSFPTEK 0.5 m Cat6 ×18 · ElecDirect 3/8" loom ×2×250 ft · CM75-0C
mounts ×400 · 4" ties ×500 · M4 brass screws+nuts ×25 + Yageo **FMF1WSFTE52-1M** 1 MΩ 1 W ×25
· Remington 10-color 22 AWG kit (**has NO PINK** — GPT corrected the brief; pink 100 ft spool
from Holland Computers eBay ~$9.99). Planning subtotal ~$803 + 18×VC500 $720.

**Outstanding before full release:** Calrad qty letter · Remington variant ETA · ZIP-date
check on CHECKOUT rows · VC500 sample pass + revision letter.

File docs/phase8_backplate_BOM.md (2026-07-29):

# Phase 8 — Complete Backplate Parts List (per lane · per pair · 32-lane house)

> ⛔ **ORDERING STRATEGY IN THIS FILE IS SUPERSEDED — 2026-07-28.**
> Work ONLY from **`phase8_ORDER_RUNBOOK_2026-07-28.md`** when placing orders. In particular:
> the §A'.2 / J4 option blocks recommending **Global Sourcing are REVERSED** (runbook Part 1:
> consign, cost is not a factor); the **A2/A3 "Hand-solder" notes are DEAD** (r10 = zero
> hand-solder, JLC places A1 and U45; flashing happens at incoming inspection); the §B
> "double-buy DECISION OPEN" note is **CLOSED → free-issue all five plugs**; §D/§E/§F never
> absorbed the PANEL-W2 deltas (D5 KN-G10 is FORBIDDEN, D7 = DDR-15G-12, gland size mix,
> E2 = 96, fan/lacing-duct/split-loom/Cat6-patch lines) — the runbook Groups 4–7 carry the
> corrected lines; and the "Board lead 4.2 wk" figure at ~:557 is the PARTS lead, not
> board-in-hand. This file remains valid as the per-lane/per-pair quantity reference.

**Rev 1 · 2026-07-25.** Everything that mounts to, or connects on, the enclosure backplate.
Board revision: **rev-D r6** (`2fd8c5e`, fab pkg `fab_revD_2026-07-27_r10`), 250 × 240 mm.
Layout: `Downloads/pair_enclosure_backplate_complete.html` Rev 2 (items ①–⑬).

**House arithmetic:** 32 lanes = **32 boards** · **16 pairs** = 16 enclosures / 16 Pis.
Spares recommended at ~10% (called out per line where it matters).

> **DECISIONS BAKED IN:** enclosure **upsized** to 36×30×8 (the three breakout modules pushed
> the panel to ~780 mm vs the 30×24's 686 mm subpanel) · **IDC20 breakouts kept** (custom adapter
> PCB declined) · **plywood backplate** replaces the steel subpanel (non-conductive, ~⅛ the cost).

> **⚠ REV-D DELTAS vs the rev-C-era lists:** **+J15** (J_SLOW_IN_C, 10-pos → plug **1840447**,
> same PN as J3) and **+J16** (J_EXT_I2C, 6-pos → plug **1840405**, same PN as J13). That's
> **7 plugs per board, not 5.** A J3/J15 swap is *electrically silent* — order those two in
> **different colours** and rely on the keying. Also: r6 populates series + clamp diodes on all
> 40 input channels, so the **1N4007 harness bodges for PBZ/DIELL are DELETED** from this list.

---

## A · Controller board and its mounting

| # | Item | Part / spec | Per lane | Per pair | ×32 house | Notes |
|---|---|---|---|---|---|---|
| A1 | Controller PCB, assembled | rev-D r6, 250×240 | 1 | 2 | **32** (+2 spare = 34) | Separate fab/PCBA PO — not costed here |
| A2 | Raspberry Pi Pico | SC0915 castellated | 1 | 2 | **34** | Hand-solder. **NOT Pico H/WH.** ⚠ Flash BEFORE soldering |
| A3 | Isolated DC/DC | TRACO **TMA-0505S** | 1 | 2 | **34** | Hand-solder, exact part, no substitution |
| A4 | Board standoffs | M3 F-F, **12 mm**, brass | 4 | 8 | **128** (+16) | MK pattern **242 × 232 mm** (rev-D moved from 242×217) |
| A5 | Standoff screws, rear | **M3 × 30** pan head ⚠️ | 4 | 8 | **128** | Through the plywood from behind into the standoff. ⚠️ **CORRECTED 2026-07-27 for ¾″ ply** — see below |
| A6 | Board screws, front | M3 × 6 | 4 | 8 | **128** | Board down onto standoff |
| A7 | Washers | M3 flat + split | 8 | 16 | **256** | |
| A8 | Centre support | adhesive PCB standoff / foam pad | 1 | 2 | **32** | Under the relay band — MK pattern leaves the J6–J11 torque zone unsupported |

> **⚠️ ¾″ PLYWOOD (19.05 mm) BREAKS THE A5 SCREW — corrected 2026-07-27.** The panel is now ¾″,
> not the ½″ (12.7 mm) originally assumed. A5's **M3 × 18 no longer reaches the standoff at all**,
> and neither does the M3 × 20 that audit finding L-09 proposed as its fix at ½″:
>
> | Screw | Engagement into the 12 mm F-F standoff | |
> |---|---|---|
> | M3 × 18 *(old spec)* | **−2.05 mm** | ❌ does not reach |
> | M3 × 20 *(L-09's ½″ fix)* | **−0.05 mm** | ❌ does not reach |
> | **M3 × 30** | **9.95 mm** | ✅ **use this** |
> | M3 × 35 | 14.95 mm | ❌ bottoms out in a 12 mm standoff |
>
> *(Allowing ~1 mm for the washer stack and head seat.)* Also revisit **E5 plywood cost and
> weight** — ¾″ is ~50 % heavier at ~7.2 kg per 1100 × 570 panel, and the sheet is dearer. Sheet
> yield is unchanged at 4 panels per 4 × 8.

> **⛔ A4 is the ONLY approved conductive contact with the board.** Nothing else may touch the
> underside (copper isolation gutters), and nothing conductive within **3 mm of the bottom edge**
> (rev-D SLOW_AUX11 copper runs to 1.28 mm from it).

## A′ · Board-side connectors — ALL JLC-PLACED as of r10 ✅

> **These are the parts that go ON the board, not the plugs that mate with it (§B).**
>
> ✅ **r10 (2026-07-27) TOOK HAND-SOLDER TO ZERO.** JLC now places all 323 parts. The
> hand-solder count went **17 → 9 → 0** across r9 and r10, eliminating ~4,150 through-hole joints
> including A1's 40 castellated Pico pads — the hardest operation on the board.
>
> ⚠️ **"JLC PLACES IT" IS NOT THE SAME AS "JLC BUYS IT."** Placement is settled; **sourcing is
> not**. For several lines we still buy the part ourselves and consign it — JLC just solders it.
> The split below is now about **who buys**, not who solders.
>
> Per JLC 2026-07-27, consigned and JLC-library parts may coexist on one order for **different**
> parts, but never for the **same** part — so each line is all-one-way. Partial stock does not help.
>
> Source of truth: `kicad/fab_revD_2026-07-27_r10/assembly/wsl-phase8b-revD-jlc-standard-pcba-part-lock.csv`.
> The hand-solder BOM in that package is now **header-only, by design**.

> **🔄 WAVE 1 (r9, 2026-07-26):** J2, J6–J11 and J14 moved to JLC, sourced from their own
> library. **DO NOT BUY THEM — that would be a double-buy**, the same trap §B carries.
> **WAVE 2 (r10, 2026-07-27):** the remaining nine — A1, J1, J3, J4, J5, J13, J15, J16, U45 —
> moved to JLC placement. Their **sourcing** is resolved per line in A′.2 below.

### A′.1 — ⛔ DO NOT BUY · JLC sources AND places these

| # | Ref | Phoenix PN | JLC part | Per board | Stock at LCSC |
|---|---|---|---|---|---|
| ~~A9~~ | J2 | 1715734 | **C480520** | 1 | 1,173 |
| ~~A10~~ | J6–J11 | 1715721 | **C480516** | 6 | 1,591 |
| ~~A15~~ | J14 | 1843622 | **C480549** | 1 | 2,481 |

⚠️ **On C480516 vs C5183929:** both are Phoenix 1715721, but `C5183929` (the number this repo
cited before) held only ~239 pcs against a **204-piece** fleet need. `C480516` is the line to
use. If JLC ever proposes swapping back, refuse.

### A′.2 — JLC PLACES THEM · but we may still have to BUY them

> **All nine are in the r10 assembly BOM with pinned C-numbers — JLC solders every one.** What is
> unresolved is *where the part comes from*. Lines JLC cannot fill from stock go to Global
> Sourcing or, more likely, we buy and consign. **Buying these is still on us; soldering them
> is not.**

| Ref | JLC part | Source decision |
|---|---|---|
| **A1** Pico | `C7203002` | ✅ **JLC** — confirmed SC0915, in library |
| **J13, J16** | `C5443576` | ✅ **JLC** — 503 in stock vs 72 needed |
| **J3, J15** | `C3585531` | ✅ **GLOBAL SOURCING** — quoted **$2.0515** (59 % under Mouser), 8 bd. *The earlier $11.31 buy-ourselves call is SUPERSEDED — see the quote block below* |
| **J4** | `C3582595` | ⚠️ **DECIDES THE SCHEDULE.** GS quoted **$1.9898 / 75 bd ≈ 15 wk**; **DigiKey holds 117 @ $5.72** (confirmed 2026-07-28). See the option table below |
| **J5** | `C3019636` | ✅ **GLOBAL SOURCING** — quoted **$1.7056** (58 % under DigiKey), 21 bd |
| **J1** | `C17373551` | ✅ **GLOBAL SOURCING** — $1.3522, 21 bd. ~$16 dearer than DigiKey but avoids consigning |
| **U45** | `C5454708` | ✅ **GLOBAL SOURCING** — $5.4409, **7 bd** (fastest line). ~$49 dearer than DigiKey but avoids consigning |

| # | Ref | Phoenix / MFR PN | Description | Per board | ×34 boards (+~10%) |
|---|---|---|---|---|---|
| A11 | J3, J15 | **1843680** | MCV 1,5/10-G-3,5 · 10-pos vertical header, **3.5 mm** | 2 | **72** |
| A12 | J4 | **1843729** | MCV 1,5/14-G-3,5 · 14-pos vertical header, **3.5 mm** | 1 | **38** |
| A13 | J5 | **1843703** | MCV 1,5/12-G-3,5 · 12-pos vertical header, **3.5 mm** | 1 | **38** |
| A14 | J13, J16 | **1843648** | MCV 1,5/6-G-3,5 · 6-pos vertical header, **3.5 mm** | 2 | **72** |
| A16 | J1 | CNC Tech **3020-20-0100-00** | 2×10 IDC/box header, 2.54 mm | 1 | **38** ✅ |
| A17 | — | **sacrificial MCV headers** | 2 × 1843680 + 2 × 1843648 + spares | — | **~10** |

> **🔎 JLC PART-IDENTITY VERIFICATION — 2026-07-27. All five resolve to the EXACT required MPNs;
> the problem is stock, not identity.** JLC proposed C-numbers for every A′.2 line and each was
> checked against its own part-detail page (not a search result — searching JLC by bare numeric
> Phoenix MPN returns false negatives).
>
> | Ref | JLC C-number | Resolves to | Stock | Need | Verdict |
> |---|---|---|---|---|---|
> | J13, J16 | **C5443576** | Phoenix **1843648** ✅ | 503 | 72 | **ACCEPT — proceed** |
> | J3, J15 | C3585531 | Phoenix **1843680** ✅ | **0** | 72 | stock-blocked |
> | J4 | C3582595 | Phoenix **1843729** ✅ | **0** | 38 | stock-blocked |
> | J5 | C3019636 | Phoenix **1843703** ✅ | **3** | 38 | stock-blocked |
> | J1 | C17373551 | CNC Tech **3020-20-0100-00** ✅ | **0** | 38 | stock-blocked |
> | U45 | — | *no match in JLC's library* | — | 38 | not sourceable via JLC |
>
> **✅ Mechanically this is the best possible answer: no substitution is on the table**, so FR-2/FR-9
> stay closed, no re-route is triggered, and the five mating plugs + CP-MSTB coding scheme + the 185
> vendor-fitted harness plugs all remain valid. The exposure is **purely procurement**.
>
> ⚠️ **Two anomalies to resolve before paying:**
> **(a) C3585531 is priced $11.31 ea** — against $2.48 for the 12-pole sibling and $1.10 for the
> 4-pole. A 10-pole costing more than a 12-pole is spot pricing, not a catalogue progression.
> 72 × $11.31 = **$814**. Requote it.
> **(b) C3582595 is listed "Assembly Type: SMT Assembly"** on a through-hole part, while its 12-pole
> sibling is correctly listed Wave Soldering. Probably bad JLC data — but it can mis-route the process.
>
> ⛔ **Zero stock on a 2-per-board connector is exactly where a contract manufacturer proposes a
> "dimensionally similar" swap at build time. Restate NO SUBSTITUTIONS per line on the order.**
>
> **All four short lines are stocked at franchised distributors** (Digi-Key alone lists 2,958 of the
> J1 header), so buying them ourselves — which §A′.2 already plans, and which the "order these first"
> block already calls the gating family — preserves the exact MPNs either way.
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

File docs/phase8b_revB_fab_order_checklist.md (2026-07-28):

# Phase 8b Rev-B Fab Order Checklist

> ⛔ **HISTORICAL — REV-B/C ONLY. DO NOT ORDER FROM THIS DOCUMENT.**
> Despite its name, this is **not** the current fab order checklist. It points at
> `kicad/fab_revB_routed_manual/JLC_UPLOAD_READY/`, which builds a **rev-C** board:
> 250 × 225 mm, no AUX4–11 bank, no J15/J16, 10 kΩ pull-ups, and **no r6 per-channel
> input protection** — landing PBZ (33 VDC) or DIELL_L/R (15.4–16 V) on it puts those
> rails across a 6 V-rated PC817 LED.
>
> **Current package:** `kicad/fab_revD_2026-07-27_r10/`
> **Current gate checklist:** `docs/phase8_revD_readiness_checklist.md`
>
> *Banner added 2026-07-25 per pre-order audit finding S3
> (`docs/phase8_revD_PREORDER_FINAL_AUDIT_2026-07-25.md`).*

Use this with the generated Rev-B package. This checklist is intentionally
order-facing: it maps the board artifacts to the JLCPCB order flow and flags
the preview checks that must happen before payment.

## Files To Use

Primary JLC upload folder:

- `kicad/fab_revB_routed_manual/JLC_UPLOAD_READY/`

Use these files from that folder in order:

- Gerbers/drill: `01_wsl-phase8b-revB_gerbers.zip`
- Clean JLC BOM: `02_wsl-phase8b-revB_BOM_JLC.csv`
- JLC CPL: `03_wsl-phase8b-revB_CPL_JLC.csv`

Transport zip for moving the upload folder as one file:

- `kicad/fab_revB_routed_manual/wsl-phase8b-revB-JLC_UPLOAD_READY.zip`

Do not upload the transport zip itself as the PCB Gerber file; unzip it and use
the three order files above.

Audit/support files:
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

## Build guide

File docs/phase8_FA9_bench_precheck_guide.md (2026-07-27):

# FA-9 bench pre-check — proving the opto front end on hardware you already own

**Written 2026-07-27.** A ~1-hour bench test on an **existing rev-B or rev-C board** that
de-risks the single largest technical unknown in the rev-D design, using **no new parts**.

> **What this is.** FA-9 asks whether the PC817B optocouplers can still pull a logic input LOW at
> rev-D's reduced LED current, hot. That question cannot be formally closed until rev-D boards
> exist — but it can be **answered early, and conservatively, on the boards already on the bench.**
>
> **What it is not.** This does **not** discharge gate FA-9. FA-9 is still executed per channel on
> the first articles. This is a pre-check that tells you now whether to expect a problem then.

---

## 1. Why an old board is a *harder* test than the real one

| | rev-B / rev-C (bench) | rev-D (real) |
|---|---|---|
| Collector pull-up `Rpu` | **10 kΩ** | 47 kΩ |
| Current the opto must sink to reach V_OL 0.66 V | **(3.3 − 0.66)/10 k = 264 µA** | (3.3 − 0.66)/47 k = **56.2 µA** |

**The bench board demands 4.7× more current from the same optocoupler.** So if a channel passes
at 1.12 mA on a 10 kΩ pull-up, the rev-D channel passes with 4.7× margin in hand. A pass here is
strong evidence; a fail here is not yet fatal, but it is the warning you want before 1,360 optos
are wave-soldered.

**Target LED current** (rev-D r6, after the series blocking diode):

| Condition | I_F |
|---|---|
| Nominal, Vw = 5.0 V | **1.34 mA** |
| FA-9 loaded minimum, TP4 ≈ 4.5 V | **1.12 mA** ← test at this |

Test at **1.12 mA**. It is the worst case that matters.

---

## 2. Equipment

- **DMM ×2** — or one meter and two passes. ⚠️ See the isolation warning in §3.
- **Bench supply** or a 9 V battery + resistor. A constant-current supply is nicer but not required.
- **Resistor assortment** around 1–5 kΩ, or a 10 kΩ trimmer, to set the current.
- **Hot-air gun or heat gun** and a way to read temperature — thermocouple, IR thermometer, or a
  cheap probe taped to the opto body.
- The **rev-B/rev-C** test-point map.

> ⛔ **Use the rev-B/rev-C TP map, never the rev-D one.** 46 refdes shifted between rev-C and
> rev-D (`ISO_WET` U37→U45, `U_WDOG` U36→U44, the R100-series watchdog family → R116–128). A
> rev-D map on a rev-B board points you at the wrong parts.

---

## 3. ⛔ The one way to damage something: bridging the isolation

The board has **two separate ground domains**, and the whole opto design exists to keep them apart:

- **`FIELD_GND`** — TP5. The field/machine side.
- **Logic `GND`** — TP2. The Pi/MCU side.

The silkscreen says **DO NOT BRIDGE TP2 TO TP5**, and it means it.

**The trap:** you are measuring `I_F` on the *field* side and `V_CE` on the *logic* side. If you
use two mains-powered instruments whose grounds are commoned through the earth pin, **you bridge
the isolation through the test gear** — and the measurement you are trying to make becomes
meaningless at the same moment you defeat the thing under test.

**Do one of these:**
- Use a **battery-powered DMM** for the field-side current, or
- Measure the two sides **sequentially**, never simultaneously with commoned grounds, or
- Use a floating/isolated bench supply for the field injection.

Confirm before you start: **TP5 to TP2 must read OPEN.** If it reads short, stop and find out why.

---

## 4. Setup

One opto channel, as built on rev-B/C:

```
  FIELD_WET_V ──► Rin (2k2) ──► PC817 LED anode
                                PC817 LED cathode ──► field pin  (J3/J4/J5 terminal)
                                                          │
                                                    [ your Rext ]   ← you insert this
                                                          │
                                                     FIELD_GND

  VCC_3V3 ──► Rpu (10k) ──► COLLECTOR NODE  ← measure V_CE here
                    ▲
   PC817 collector ─┘
   PC817 emitter ──► logic GND
```

1. Power the board normally. Let `FIELD_WET_V` settle and **record TP4**.
   *(Expect a high reading unloaded — the TMA-0505S is unregulated and rises with no load. It
   falls once the channel draws current. That is normal, not a fault.)*
2. Pick **one** channel on a landed field connector. Note which refdes opto it is.
3. Wire your DMM **in series** between that field pin and `FIELD_GND`, through `Rext`.
4. Put the second meter (or your second pass) on the **collector node** referenced to **logic GND**.

---

## 5. Procedure

### Step 1 — set the current
Adjust `Rext` until the series DMM reads **1.12 mA ±0.02**. Record the value of `Rext` you needed.

### Step 2 — cold reading
Record `V_CE` at the collector node.

### Step 3 — heat
Warm the opto body to **≥ 70 °C** and hold it there. Let the reading settle — 30 s or so.
Re-record `V_CE` **and** re-check `I_F` (it drifts as the LED warms; re-trim `Rext` back to
1.12 mA if it has moved).

### Step 4 — repeat on 3–4 channels
Optos vary part to part. One channel proves nothing about spread. Do at least three, and include
one from each opto bank if the board has more than one.

### Step 5 — optional, worth doing
Repeat at **1.34 mA** (the nominal case) to see how much the margin improves off the worst case.

### Data table

| Channel / refdes | Rext (Ω) | I_F (mA) | V_CE cold (V) | Temp (°C) | V_CE hot (V) | Pass? |
|---|---|---|---|---|---|---|
| | | 1.12 | | | | |
| | | 1.12 | | | | |
| | | 1.12 | | | | |

---

## 6. Pass criteria

| Result | Meaning |
|---|---|
| **V_CE < 0.66 V hot, on every channel** | **PASS.** The rev-D channel has ~4.7× more margin than this proved. Expect FA-9 to pass. |
| V_CE 0.66–1.0 V hot | **MARGINAL on the bench board.** rev-D would still likely pass on the 47 kΩ, but stop and re-derive before ordering optos in fleet quantity. |
| V_CE > 1.0 V hot, or it will not pull down at all | **INVESTIGATE.** Do not assume the design is wrong — first confirm `I_F` really is 1.12 mA, that you are on the right collector node, and that the isolation is intact. |

**0.66 V is the design's V_OL assumption** — the number behind the 56.2 µA sink requirement in
the 47 kΩ arithmetic.

---

## 7. If it fails

Do not jump to replacing optos. The cheap fixes come first and they are all **0805 SMD**:

1. **Lower `Rin`** (2k2 → smaller) to raise LED current. 40 per board, SMD, cheap rework.
2. **Raise `Rpu`** beyond 47 kΩ to reduce the required sink — but this eats noise margin and the
   RC edge budget, so re-derive both before touching it.
3. **Replace the optos** — 40 through-hole parts per board. This is the expensive one and the
   reason the pre-check exists at all.

---

## 8. What this proves, and what it does not

**Proves:** that a PC817B of this type, at rev-D's operating current and hot, can sink enough to
make a valid logic LOW — with a 4.7× conservatism built into the test.

**Does not prove:**
- **Lot variance.** JLC pulls its own reel. This tests the *part type and rank*, which is the
  actual open question — the UMW part lacks a guaranteed minimum CTR at this current — but not
  the specific reel JLC will use.
- **Per-channel behaviour on rev-D.** Only FA-9 on real boards does that.
- **Edge speed.** The ≤ 100 µs transition criterion needs a scope and is a separate FA-9 step.
- **End-of-life drift.** Aging reserve is in the FA-9 numbers, not in a bench snapshot.

Record the numbers in the run log either way. A clean pass is evidence worth keeping; a marginal
result is a finding that changes the fleet decision.

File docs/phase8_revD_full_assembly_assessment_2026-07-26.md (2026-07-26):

# rev-D full-assembly assessment — "let JLC solder everything"

Date: 2026-07-26 · Board: rev-D r8, 250 × 240 mm, 4-layer · Order: 34 boards (fleet)
Question: can JLCPCB solder all 17 hand-solder placements, at what cost, and what breaks?

---

## 1. ANSWER

**YES-EXCEPT-1 — and not as a service-tier upgrade.** JLC can place 16 of the 17; the only
exception is **J1**, and it is excluded because its part identity has never been verified
(BOM status: "Candidate — verify body/keying"), not because JLC lacks the capability. The
premise behind the ask is wrong in a way that saves money: **there is no upgraded PCBA tier to
buy.** JLC offers exactly two assembly services, Economic and Standard; this order is already
on Standard (mandatory anyway above Economic's board-count cap), and Standard already
through-hole-assembles 190 joints per board today — the 40 PC817 DIP-4 optos and 6 G5LE
relays. JLC's own FAQ states that parts flagged "wave soldering" in its library "will be
assembled manually," so the new connector joints use the identical process the board already
relies on. The measured labour delta for moving all 17 is **$71–79 across the entire fleet**
($2.09–2.32/board). The real constraint is not process and not price — it is **sourcing**: 6
of the 10 distinct part types have no confirmed JLCPCB library entry and must route through
Global Sourcing or consignment, which adds $125–340 in channel fees, a mandatory JLC
engineering-approval step, and 1–3 weeks of serialized logistics. Spend the money on the
sourcing problem, not on a tier that does not exist.

---

## 2. THE SPLIT I RECOMMEND

Three waves, ordered by risk and lead time. **Wave 1 is free and should be done regardless of
what the owner decides about the rest.**

| Ref | Qty | MPN | Verdict | Wave | Why |
|---|---|---|---|---|---|
| J2 | 1 | Phoenix 1715734 (MKDS 1,5/3-5,08) | **JLC** | 1 | In JLC library as **C480520**, Wave Soldering, Economic+Standard. Unique PN, uncoded, unkeyed. LCSC price ~$0.51 @30+ vs $2.25 DigiKey estimate in `phase8_revB_preorder_parts.csv` — cheaper than buying it ourselves. |
| J6–J11 | 6 | Phoenix 1715721 (MKDS 1,5/2-5,08) | **JLC** | 1 | In library as **C5183929** (239 pcs — thin) and, better, **C480516**, same Phoenix MPN, 3,214 pcs. Uncoded, unkeyed, no flash gate. See §3 note: the repo's BOM cites the thin line. |
| J14 | 1 | Phoenix 1843622 (MCV 1,5/4-G-3,5) | **JLC** | 1 | In library as **C480549**, Wave Soldering, Economic+Standard, 451 pcs. It is *not* one of the FA-8 coded pairs — safety-loop header, no rib cut. LCSC ~$0.84 @30+ vs $1.25 DigiKey. |
| J3 | 1 | Phoenix 1843680 (MCV 1,5/10-G-3,5) | **JLC — conditional** | 2 | Not resolved in the library by MPN search (search-by-numeric-MPN gives false negatives — see §3). Needs a Global Sourcing quote or consignment. Coding rib is cut **post-solder on the board's own header** per FA-8 step 2, so JLC ships one uncoded PN. |
| J4 | 1 | Phoenix 1843729 (MCV 1,5/14-G-3,5) | **JLC — conditional** | 2 | Same route as J3. Uncoded, unique pole count. |
| J5 | 1 | Phoenix 1843703 (MCV 1,5/12-G-3,5) | **JLC — conditional** | 2 | Library entry **C3019636** exists but shows only ~7 pcs — cannot cover 34. Global Sourcing or consignment. |
| J13 | 1 | Phoenix 1843648 (MCV 1,5/6-G-3,5) | **JLC — conditional** | 2 | Same route as J3. Coded vs J16 post-solder. |
| J15 | 1 | Phoenix 1843680 | **JLC — conditional** | 2 | Same PN as J3. One bin, one BOM line, qty 2/board. Coding is a post-solder cut, so there is no two-bin problem. |
| J16 | 1 | Phoenix 1843648 | **JLC — conditional** | 2 | Same PN as J13. Same reasoning. |
| U45 | 1 | TRACO TMA 0505S | **JLC — conditional** | 2 | Library entry **C5454708** exists at ~30 pcs against a need of 34 (38 with spares) and is OOS at LCSC retail. **Do not let JLC substitute** — the lock says "no substitution without pinout and isolation review." Consign from DigiKey 1951-1003-ND (5,964 in stock, $4.32/10+) or Global Source the exact PN. Rides along with the Wave-2 parcel at ~zero marginal logistics. |
| A1 | 1 | Raspberry Pi SC0915 (Pico) | **JLC** | 3 | Not a THT part — `Module:RaspberryPi_Pico_SMD`, 96 SMD pads, 0 drills. Raspberry Pi designs it for module reflow. Requires a **pinned C-number** and a silkscreen photo gate (§5). See §3 for why "flash before soldering" is a dead argument. |
| **J1** | 1 | CNC Tech 3020-20-0100-00 | **HAND — for now** | — | The only genuine exclusion. Status is "Candidate — verify body/keying"; it has never been checked against the KiCad `IDC-Header_2x10_P2.54mm_Vertical` footprint, the mating ribbon socket is unbought, and the crimp orientation is flagged "confirm before crimping." **Escalation path:** J1 is *not* Locked, so re-specifying it to a library-native DIN 41651 box header (e.g. BH254V-20P / C492444, 10,481 pcs, $0.12) is legitimate and would move 20 joints/board — 680 fleet-wide — into Wave 1. That is an owner call, not mine (see §6 Q4). |

**Totals:** Wave 1 = 8 placements, 19 THT joints/board. Wave 2 = 7 placements, 61 THT joints/board.
Wave 3 = A1, 96 SMD pads. J1 stays hand = 20 joints/board, 680 fleet-wide.

### The case for keeping J1 hand-soldered
It is the one part on the list whose *identity* is unproven. The board-side footprint is
generic (stock KiCad, DIN 41651 / IEC 60603-13, 1.0 mm drill on 1.7 mm pads at 2.54 mm pitch),
so any conforming 20-way box header drops in — but that also means locking the wrong shroud or
key orientation is invisible until a ribbon is presented. The rev-B bring-up guide is explicit:
"the header solders fine either way, but get pin-1 orientation right relative to the Pi." That
verification is 15 minutes of work against the existing rev-B board #1, and until it happens
J1 should not be committed to 34 boards by anyone — JLC or owner.

### The case for sending A1 (the Pico) — this is the finding that changes the plan
1. **The "flash before soldering" note is stale rev-C geometry.** In rev-D, A1 sits at
   (100, 33) rot 0 with the micro-USB facing the board's own y=0 edge and 5.70 mm of empty
   board in front of it. J1 was moved from (126, 10) to (135.5, 10) — 25.4 mm of lateral
   separation, with J2 physically interposed. Nothing occupies x 88–114 below y 5.7. The
   16 × 12 × 40 mm USB keep-out (D12) is drawn on Dwgs.User and is on the G12 inspection list.
   The rev-C jam condition no longer exists.
2. **Pre-flashing buys exactly one flash cycle, then expires.** The arming flags
   (`CAM_SA_STOP_ENABLED`, `CAM_SA_TRIP`, `CAM_TA1_TRIP`, `INTERLOCK_ECHO_ENABLED`,
   `MOTION_NO_RUN_ENABLED`) are compile-time; the cutover image does not exist yet and will be
   a different hash-locked UF2. The repo states it plainly: the compiled-OFF detectors and "?"
   polarity sentinels "guarantee at least one reflash per board after Phase 0, possibly
   in-enclosure." **Post-assembly USB flashing is already mandatory fleet-wide.** Hand-soldering
   A1 postpones the problem by one flash and leaves you in the identical position.
3. **Two independent recovery paths survive reflow.** The shaved right-angle micro-B cable is
   proven — it flashed a soldered rev-B board whose geometry was strictly worse. And the Pico's
   own SWCLK/GND/SWDIO castellated holes are on the module's top face at the end opposite the
   USB, in a courtyard whose nearest neighbour is 14 mm away; audit L-03 already relies on that
   path to close a different gate.
4. **Cost of insisting otherwise:** 34 hand-soldered 40-pad castellated LGA modules — the
   hardest single operation on the board, with pads partly under the module body — to protect a
   mitigation that has already expired. That is roughly 6–9 hours of the highest-risk soldering
   in the build, bought for nothing.

**Caveat, accepted knowingly:** FA-4 (unmodified micro-B seats with the J1 ribbon mated) has
never been run and cannot be run before a fleet PO commits all 34 A1 placements. Under the
recorded G15 fleet-quantity decision there is no first article to gate on. Record this as an
explicit pre-order risk acceptance with the shaved cable + module-SWD rig as the named
contingency. Do not pretend it was tested.

---

## 3. BLOCKERS

Ranked by whether they stop the order.

### B1 — The fleet order is already blocked, independent of this decision (**HARD**)
`docs/phase8_revD_PREORDER_FINAL_AUDIT_2026-07-25.md` records that the G15
EXPERIMENTAL-ORDER acceptance line at `docs/phase8_revD_readiness_checklist.md:350` is blank,
and that **both** the 0.4807 mm field-pin clearance (vs IPC-2221B's 0.6 mm) and the PC817B CTR
item are dispositioned to the *fleet revision* — i.e. 34 boards would be built to a revision
the project has already committed to changing. Nothing in this assessment moves that. If G15
is not signed, the assembly question is moot.

### B2 — 6 of 10 part types have no confirmed library entry (**HARD until quoted, then routine**)
Confirmed present in JLC's assembly library via part-detail pages (the authoritative source):
1715721 (C5183929 / C480516), 1715734 (C480520), 1843622 (C480549), 1843703 (C3019636, stock ~7),
SC0915 (C9900019762) and Pico (C7203002), TMA0505S (C5454708, stock ~30).
Unresolved in either direction: **1843680, 1843729, 1843648, CNC Tech 3020-20-0100-00.**

> **Method warning — do not repeat this mistake.** Searching JLC/LCSC by bare numeric Phoenix
> MPN produces guaranteed false negatives. `jlcpcb.com/parts/componentSearch?searchTxt=1843622`
> returns "0 Found" while `jlcpcb.com/partdetail/C480549` returns the part, in stock, marked
> Wave Soldering / Economic and Standard. **Absence of a search hit is not evidence of absence.**
> Resolve by C-number or by a free Global Sourcing quote.

Route options, both with a mandatory JLC engineering-approval step *before* parts move:
- **Global Sourcing** (self-serve, JLC buys the exact MPN from Western distributors, 9–20
  business days + 1–3 day review): $20 commodity inspection per part type, 3–30 % customs duty,
  $0.017/pin loose handling (max $0.078/component). **Non-cancellable once paid.**
- **Consignment** (owner buys, ships to Zhuhai): $45 customs service (<5000 CNY parcel), owner
  pays DDP freight, JLC explicitly disclaims quality liability for consigned parts, and
  "only parts with JLC number can be consigned" — everything else needs written approval first.

Quote Global Sourcing **first** — it is free, non-binding, and it also reveals whether JLC
beats DigiKey's historically 8–20 week Phoenix lead time on 1843680/1843703.

### B3 — JLC's own consignment T&C contradicts itself on mixing (**HARD — settle by support ticket**)
The consignment Terms & Conditions state consigned parts "can only be used together with global
sourcing parts, instead of JLCPCB parts." The how-to page reads it per-part ("for the same part
A, JLC parts cannot be mixed with consigned parts… you can use JLC parts for part A and
consigned parts for part B"). **If the order-level reading governs, consigning 6 part types
forces all 27 existing JLC-library lines onto Global Sourcing** — a far larger cost and
schedule hit than anything else in this document, and the plan fails at any price. Get this in
writing from JLC support before spending a dollar.

### B4 — Substitution is forbidden; say so in writing before requesting a quote (**PROCESS**)
If JLC cannot source an exact Phoenix PN, the answer is "that refdes stays hand-solder," **not**
"substitute an equivalent." Substituting an MCV header cascades: FR-2 and FR-9 (footprint-vs-
datasheet, the `_D1.4` locals) invalidate → netlist regen → placement + DRC → **full re-route**
(the run log records that the wider J13.4 `_D1.4` pad already pinched the VCC_3V3 IN2 trunk to a
0.4 mm gap once) → and it invalidates the mating plugs 1840447/1840489/1840463/1840405/1840382,
the CP-MSTB coding scheme, FA-8's entire refusal matrix, and the harness RFQ's 185 vendor-fitted
plugs. That is a board re-spin plus a harness re-spec, not a sourcing choice.

### B5 — FA-10 cannot be executed as written (**MEDIUM — rewrite required**)
FA-10 is an *ordering* gate, not a test: solder one MCV header, verify insertion force and
solder fill, **then** do the remaining six. It is the only physical proof of the project-local
`_D1.4` footprint, which has never been built. If JLC solders all seven, that gate disappears
and 2,108 joints land on unproven geometry at once. Replace it with an **incoming-inspection**
step on board #1 (bottom-side fillet + barrel fill on all 62 T8 barrels, before boards 2–34 are
unpacked). Note the drill is defensible: 1.4 mm is exactly the IPC-2222 Level A number for a
0.8 × 0.8 mm pin (1.131 mm diagonal + 0.25 mm), and JLC's annular-ring floor is 0.15 mm against
this footprint's 0.30 mm — 2× margin. Separately, **the FR-9 justification text is wrong**:
Phoenix's own sheet for 1843680 specifies a **1.2 mm** hole, not 1.4 mm. Fix the prose, keep
the drill.

### B6 — G12 Part B: 10 new part classes with zero CPL rotation precedent (**MEDIUM**)
The exporter has no rotation-correction table — `"Rotation": f"{float(row['Rot']):.6f}"` is a raw
KiCad pass-through — and R-7 is retired "by prior-build inference for the optos/diodes/relays
only." A1 and the connectors are in neither class. A systematic 180° error on the six single-row
MCV headers is batch-wide and puts wire entry facing inboard on 34 boards. **Mitigation:**
require JLC's rendered placement preview / 3D check before payment, and annotate expected
orientation per refdes in the r9 README.

### B7 — Sacrificial header stock for FA-8 (**LOW — buy it either way**)
FA-8 makes the header side of the code by cutting a rib at J3 pole 1, J15 pole 10, J13 pole 1,
J16 pole 6 — 4 cuts/board, 136 fleet-wide — and step 1 requires proving it on a sacrificial
part first. This is **unchanged** by the decision: Phoenix designs MCV as a vertical shrouded
header whose coding features face away from the PCB, and FA-8 step 2 already says to cut "on the
board's own headers," i.e. post-solder. But with JLC holding the production headers there are
zero loose ones. **Buy ~10 loose sacrificial MCV headers (2 × 1843680, 2 × 1843648, spares) in
the same PO.** Explicitly reject pre-cutting ribs before consignment: it would split 1843680
into two coded SKUs (J3 @ pole 1, J15 @ pole 10) and 1843648 into two more, and a feeder swap
would then produce a silently mis-keyed board.
Add one line to FA-8: **shear with flush cutters, board supported, never pry** (0.30 mm annular
rings on unproven barrels), and clear swarf before running the refusal matrix.

### B8 — Edge rails and depanelization order (**LOW — one question to JLC**)
Standard PCBA lists edge rails as "Necessary." Today the rail has somewhere safe to go
(minimum courtyard-to-edge over JLC-placed parts: top 10.25 mm, left 20.75 mm, right 53.80 mm,
bottom 0.63 mm). Fully populated, every edge falls under 5 mm (top 0.52 mm at U45, bottom
0.63 mm at U43, left 4.25 mm at J15, right 2.29 mm at J6). The rail *requirement* does not
change — it serves the SMT pass — but if the rail is snapped off **after** connector insertion,
break stress runs within 0.5–4.3 mm of a connector body on 1.4 mm barrels. Ask JLC in writing
whether depanelization precedes or follows THT insertion.

### Non-blockers (raised and dismissed, evidence in §7)
Wave-solder thermal risk (JLC hand-assembles THT), FA-8 destruction (post-solder cut is the
Phoenix-sanctioned order), the two-bin coding dilemma (headers ship uncoded), Phoenix backorder
(1843703 shows 2,139 at DigiKey, 1843680 shows 774 across DigiKey+Mouser — the backorder note
is 6.5 weeks stale and its own mitigation is printed two lines below it), board size
(250 × 240 mm is inside Standard's 70 × 70 – 460 × 500 mm single-board range; the 250 × 250 mm
figure is the *panel* limit — so do **not** let JLC panelize).

---

## 4. COST — delta vs status quo at 34 boards

### Assembly fees (VERIFIED against JLC's published price page)
Status-quo Standard PCBA assembly stack: **$213.36** fleet.

| Item | Basis | Fleet cost |
|---|---|---|
| New manual (THT) joints | 101 joints/bd × 34 = 3,434 × $0.0157 | **$53.91** |
| A1 SMD joints | 96 pads × 34 = 3,264 × $0.0016 | **$5.22** |
| Feeder loading, 10 new part types | 10 × $1.50 | **$15.00** |
| **Full-move delta** | | **$74.13** ($2.18/board) |
| Same, at the $0.0173/joint rate JLC quotes in its FAQ | | **$79.63** |
| *Wave 1 only* (J2 + J6–J11 + J14) | 19 joints/bd = 646 × $0.0157 + 3 feeders | ***$14.64*** |

Fleet totals stay at ~34,578 placed joints — well under JLC's 50,000-joint tier-1 breakpoint,
so **no price-tier change occurs.** Wave/THT adds "+1 more day" to build time. **Any quote
materially above ~$80 of incremental labour is priced on parts sourcing or NRE, not process.**

### Parts-channel fees (the real money) — ESTIMATED, ranges are honest
| Route | Composition | Fleet cost |
|---|---|---|
| Global Sourcing, 6 unlisted types | $20/type inspection ($120) + 3–30 % duty on ~$632 of parts ($19–190) + loose handling (~$23) | **$162–333** |
| Consignment, 6 unlisted types | $45 customs service + DDP express freight US→Zhuhai (**estimated $80–150, not quoted**) | **$125–195** |
| Contingency: PCBA "Large Size" fee | $59.23/order — trigger dimension **not published** by JLC; board is 600 cm², under the 650 cm² *fab* threshold | **$0–59** |

**Parts cost itself is not a delta** — the owner buys these connectors either way. Only channel
fees move. Wave 1 has **zero** parts-channel cost: JLC buys those three PNs the same way it
already buys the PC817s.

### What the money buys
141 hand joints/board × 34 = **4,794 hand joints eliminated** (or 4,114 if J1 stays hand).
At 60–90 min/board including insertion, squaring, and the post-solder visual/continuity checks
this board's safety story requires, that is **34–51 hours of owner bench time**, midpoint ~42 h.

**Bottom line:** ~$250–475 of cash for ~42 hours — roughly $6–11/hour. The decision should be
made on schedule and batch-risk grounds, not on this number. Secondary benefit: it fixes the
solder half of audit finding M-14 (a spare PCBA is currently not a swappable spare — 17 hand
placements plus a Pico flash, unbudgeted), turning a 4–7 h outage-pressure build into a ~1 h
swap.

---

## 5. WHAT HAS TO CHANGE

The split is a **hardcoded refdes set** with seven fail-closed `SystemExit` guards. Nothing
fails silently — the export simply refuses to run until every constant is updated coherently.

### `scripts/export_fab_revD.py` (~80 edited lines)
| Line | Constant / block | Full move | Wave 1 only |
|---|---|---|---|
| :97 | `EXPECTED_HAND_SOLDER = 17` | → `1` (J1 stays) | → `9` |
| :98 | `EXPECTED_JLC_PLACED = 306` | → `322` | → `314` |
| :99 | `EXPECTED_JLC_LINES = 27` | → `43` natural, **37 with 7 aliases** (recommended) | → `35` natural, **30 with aliases** |
| :142–148 | `HAND_SOLDER_REFS` | → `{"J1"}` | remove J2, J6–J11, J14 |
| :484 ff. | `HAND_SOLDER_ROWS` | trim to the J1 row | remove 3 rows |
| :~200–700 | `PART_LOCK` | **+9 primaries + 7 aliases**, each needing a real pinned C-number | +3 primaries + 5 aliases |
| :201, :342 | `locked_spec` strings reading "wave solder" | correct — JLC assembles THT **manually**; this is the project's own hardcoded text, not JLC's | same |
| :1364–65 | README literal naming retired UNI-ROYAL 10M **C26108** while the part-lock CSV in the same package says FOJAN **C2933281** | **fix — independent defect (F8)**, exactly the class the exporter's own comment says it fixed for counts | same |
| :1401 | README literal `"Hand-solder after JLC: A1, J1-J11, …"` | rewrite | rewrite |
| :20–21 | module docstring counts | update | update |

Guards that trip until all of the above is coherent: `:715` (×N, `No JLC part lock for …`),
`:1137` (hand count), `:1140` (JLC placed count), `:1162` (BOM quantity sum), `:1164` (line
count), `:1291` (hand BOM refs vs exclusion set), `:1394` (MATCH-AT-UPLOAD / empty C-number ban).

**Sequencing constraint:** `:1394` bans a JLC line without a pinned C-number, so **the code
change cannot be written until procurement returns real part numbers.** Do B2 first.

**A1 specifically** needs: a pinned C-number, an identity assert alongside the existing
relay/MCP/D_PROT/2N7002/47k/1N4148 hard locks, and a **G12 photo gate** — a photograph
confirming the silkscreen reads "Raspberry Pi Pico" (RP2040), not "Pico 2". JLC's library
carries six SMT-assemblable Pico entries including **C41407547 (Pico 2 / RP2350)**, and the
firmware is RP2040-only (`build_options.pico_board = "pico"`, UF2 `d5570efd…`). See §6 Q3 for
the C-number choice.

### Unchanged — this is why the job is small
`EXPECTED_NETLIST_PARTS = 391`, `EXPECTED_DNP = 68`, `EXPECTED_PLACED = 323`. **The board does
not change.** No re-route, no re-place, no netlist regen, no ERC re-run. CPL rotations for all
17 already exist in the master CPL (`…-cpl.csv`, 324 lines) — the exporter merely filters them
at `:1241`. **Zero new CPL code.** No test file needs editing:
`tests/test_fab_package_notes.py` scrapes only `EXPECTED_DNP` and `EXPECTED_NETLIST_PARTS`.

### Package: an r9 is MANDATORY
`:945` — `REFUSING TO RUN: output directory already exists`. So the change ships as
`kicad/fab_revD_2026-07-27_r9/`. Three tests then assert `len(dirs) == 1` ("exactly one rev-D
fab package may be current"), and `_current_fab_dirs()` exempts only directories carrying a
`_SUPERSEDED*` marker. **r1–r7 each carry one; r8 does not.** Create
`kicad/fab_revD_2026-07-26_r8/_SUPERSEDED_DO_NOT_UPLOAD.txt` or three tests fail. r8 is already
git-tracked (47 files).

### Docs
- `scripts/generate_first_article_docs_revD.py:720` — **FA-10 rewrite** (ordering gate →
  incoming inspection on board #1). FA-10 is *generated*; edit the generator, not the .md.
- `docs/phase8_revD_first_article_pack.md` — regenerate; add the FA-8 cutting technique line.
- `docs/phase8_backplate_BOM.md` — move the transferred refs out of §A′ owner-buy into a
  consignment/Global-Sourcing section; **add ~10 sacrificial MCV headers**; leave the A2
  "Flash BEFORE soldering" note in place until FA-4 passes (per L-10's standing disposition),
  but stop using it as an argument.
- `docs/phase8_revD_readiness_checklist.md` — reopen G11, G12 Part A, G14; add the B3
  consignment/mixing gate and the B8 depanelization question; record the FA-4 risk acceptance.
- `docs/phase8_revD_run_log.md` — correct the FR-9 justification prose (Phoenix specifies
  1.2 mm; 1.4 mm is the IPC-2222 Level A figure and is correct — the *reason* given is wrong).

### Gates
**Re-open:** G11 (export), G12 Part A (package inspection — drill report T8, silk, K1–K7 pad-net
map, review plots), **G12 Part B (CPL rotations — the real risk, see B6)**, G14 (checklist
sign-off). Both G12A and G14 were closed on 2026-07-26 against package r8 and are package-scoped.
**Do NOT re-open** (no board change): G2, G3, G4, G5, G9, G10.

### Effort
~2 h code + ~1 h docs + ~1 h re-export and gate re-verification = **half a day of engineering**,
gated behind the procurement answer, which is the long pole (Global Sourcing review 1–3 business
days, sourcing 9–20 business days; or consignment freight + customs ~1–1.5 weeks).

---

## 6. DECISION FOR THE OWNER

**Do this today, unconditionally:** move **J2, J6–J11, J14** into the JLC BOM. $14.64 fleet,
zero logistics, zero new risk, no consignment, no customs, 646 joints gone. They are library-
native, in-stock, unique-PN, uncoded and unkeyed. This is free money and it is the same code
change as the full move, just smaller.

Then I need answers to five things:

1. **Is G15 signed?** The fleet order is blocked on the blank EXPERIMENTAL-ORDER acceptance line
   at `readiness_checklist.md:350`, with the 0.4807 mm clearance and PC817B CTR both
   dispositioned to the fleet revision. Everything below is moot until that is resolved. Yes/no.

2. **Do I open a JLC support ticket on the consignment/mixing contradiction (B3) before anything
   else?** If the order-level reading governs, this whole plan costs 10× what §4 says. It is one
   email and it gates the decision. Yes/no.

3. **Which Pico C-number do I pin for A1?** Options: **C9900019762** (explicitly SC0915,
   Extended, Economic+Standard — but its manufacturer field reads "JLCPCB Assembly," an internal
   SKU class with no published stock or price) or **C7203002** (RP2040 Pico, ~834–1,647 in
   stock, ~$5.87–6.16, **Standard only** — tier-compatible) whose library MPN string is just
   "PICO" and does not distinguish the bare module from a Pico H with pre-soldered headers,
   which the lock forbids. My recommendation: **ask JLC to confirm the exact variant on
   C7203002, pin whichever they confirm as the bare castellated module, and require the
   silkscreen photo gate regardless.** Your call, or delegate it to me to resolve with JLC.

4. **J1 — re-spec to a library part, or keep hand-soldering it?** It is *Candidate*, not Locked,
   so re-specifying is legitimate. A library DIN 41651 box header (C492444 class, 10,481 pcs,
   $0.12) moves 680 joints into Wave 1. Cost of saying yes: you must also pick and buy the
   matching 2×10 ribbon socket and verify pin-1/keying against the existing rev-B board #1
   (~15 min). Cost of saying no: 680 hand joints and J1 stays the last hand-solder operation
   on every board. **My default is no — keep it hand — until the keying is verified either way.**

5. **Do you accept the FA-4 risk acceptance in writing?** Under G15 fleet quantity there is no
   first article, so JLC placing A1 commits 34 Picos before anyone confirms an unmodified
   micro-B cable seats with the J1 ribbon mated. The geometry is measured clear (25.4 mm from
   J1, 5.70 mm of empty board in front of the USB, D12 envelope drawn) and there are two proven
   fallbacks (shaved right-angle micro-B, module SWD pads). **I recommend accepting it** — the
   alternative is 34 hand-soldered castellated modules to protect a mitigation that expires at
   the Phase-0 reflash anyway. But it must be a recorded acceptance, not silence.

**Two things I will do regardless of your answers**, because they are defects found in passing:
fix the r8 README's retired 10M part-number literal (`export_fab_revD.py:1364–65` — README says
UNI-ROYAL C26108, the part-lock CSV in the same package says FOJAN C2933281), and add the
missing `_SUPERSEDED` marker to r8 the moment an r9 exists.

---

## 7. REFUTED / CARRIED-UNVERIFIED — brief

### Refuted (do not re-raise)
- **"Buy an upgraded PCBA tier."** No such tier. Economic and Standard only; already on Standard,
  which is mandatory at 34 boards. JLC assembles THT **manually**, not by wave — its own FAQ
  says parts flagged "wave soldering" in the library "will be assembled manually." The entire
  wave/pallet/thermal risk class is out of scope. (The "wave solder" strings in our own BOM are
  hardcoded in `export_fab_revD.py:201,342` — our text, not JLC's.)
- **"6 of 10 part types are absent from the JLC library."** The search method producing that
  result gives guaranteed false negatives — JLC's own search box returns "0 Found" for parts JLC
  sells (`1843622` → 0 found; `partdetail/C480549` → in stock). Verified-absent count is **zero**;
  4 types are confirmed present, 6 are unresolved in either direction.
- **"FA-8 is destroyed / the coding rib must be cut before soldering."** No repo document
  specifies cut-before-solder. FA-8 step 2 says the cut is made "on the board's own headers,"
  and step 3's refusal matrix and step 4's per-position silk check are inherently post-assembly.
  Zero process steps change.
- **"J3/J15 and J13/J16 need two consigned bins."** Headers ship uncoded; the pair is
  distinguished only by a post-solder cut. One PN, one bin, one BOM line at qty 2/board. The
  KiCad values are already distinct (`J_FAST_IN` vs `J_SLOW_IN_C`), so they default to separate
  BOM lines anyway — aliasing is opt-in.
- **"Phoenix headers are backordered; consignment serializes an 8–20 week lead time."**
  `cowork_cart_handoff.md` is 6.5 weeks stale, is a rev-B document, records the backorder at
  qty 5, and prints the mitigation ("re-ordering at Mouser") two lines below. Live: 1843703 shows
  2,139 at DigiKey; 1843680 shows 52 at DigiKey + 722 at Mouser. The real serialization leg
  against in-stock drop-shipped parts is ~1–1.5 weeks.
- **"FA-10's 1.4 mm drill is unproven, non-standard geometry."** 1.4 mm is exactly IPC-2222
  Level A for a 0.8 × 0.8 mm pin (1.131 + 0.25 = 1.381). Annular ring is 0.30 mm against JLC's
  0.15 mm floor. rev-C assembled at 1.2 mm and pins fit; 1.2 → 1.4 mm strictly relaxes insertion.
  What survives is only that FA-10's *sequence* can no longer run (B5) and that the FR-9
  justification prose is factually wrong.
- **"There is no second flash path / rev-D has no SWD."** What was dropped in rev-C is a
  *carrier-side* SWD breakout header. The Pico's own castellated SWCLK/GND/SWDIO holes survive
  reflow and audit L-03 already relies on them. `picotool` also reaches any assembled board via
  BOOTSEL/PICOBOOT — only the `-f` force-reboot path needs USB-CDC, which is compiled out.
- **"Staged 2-board pilot then 32."** Re-litigates an owner decision recorded 2026-07-26 at
  `readiness_checklist.md:448-453`: proceed at fleet quantity, reaffirmed after exposure was laid
  out in full. Also costs a second setup, a second consignment shipment and 3–5 weeks.
- **"A1 is a through-hole part."** It is `Module:RaspberryPi_Pico_SMD`, `(attr smd)`, 96 SMD pads,
  0 drills. 16 of the 17 are the THT question; A1 is not.
- **"JLC places 7 G5LE relays."** Six. K7 (M1 channel) and J12 (7th MKDS block) are both DNP.
  Current JLC manual-joint count is **190/board**, not 195 — this is the basis for the §4 costs.

### Carried unverified (labelled as such — do not treat as fact)
- **JLC's overseas consignment terms** are read from published help pages, not confirmed with
  support for this order. The mixing clause (B3) is the load-bearing unknown.
- **The BOM cites a thin LCSC line for J6–J11.** C5183929 carries ~239 pcs against a need of
  204–224; **C480516** is the same Phoenix MPN with ~3,214. Worth fixing regardless of this
  decision. Not independently re-verified today.
- **PS-4/PF-6: A1's footprint puts solder paste on the D1/D2/D3 lands**, so reflow may wick
  solder into the Pico's own DEBUG through-holes, degrading the SWD fallback to a wick-and-header
  operation. Pad census (43 paste-only / 43 Cu+Mask / 10 Cu+Mask+Paste) is from the board file;
  the wicking behaviour is inferred, not observed.
- **Do not buy JLC's programming service.** It requires "the programming interface definition
  reserved on the board" (there is none — the interface is the module's USB plus a button) and a
  HEX/BIN file, while `firmware/rp2040/release/` contains only signed `.uf2`. It would also break
  the hash-locked chain of custody and the image is not cutover-ready anyway. $7.86 + $7.86/h,
  and it solves nothing.
- **Freight, duty and bare-PCB prices in §4** are estimates from published rate cards, not live
  quotes. DDP means the sender pays Chinese import duty and VAT, which the $80–150 estimate
  excludes.
- **Attrition percentage** JLC requires on consigned/global-sourced parts is referenced in their
  docs but never stated numerically. Under-shipping stalls the whole order. Ask before sizing a
  parcel — it matters for the thin C3019636 (~7) and C5454708 (~30) lines.
- **Whether JLC hand-solders *consigned* THT parts at the same $0.0157/joint manual rate** is not
  documented. The §4 assembly delta assumes it does.
- **Whether JLC's DFM will demand an edge rail** given the 0.63 mm bottom-edge part (U43) — audit
  open question R-9, answerable only by the real upload preview and quote.

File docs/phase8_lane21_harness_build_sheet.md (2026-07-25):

# Lane 21 Machine-Interface Harness — CUT-AND-CRIMP BUILD SHEET (Candidate C)

> **⚠ CORRECTION 2026-07-21 (Codex NO-GO audit finding H7) — MC 1,5 termination data in
> this sheet was WRONG vs the Phoenix data for the MC 1,5/..-ST-3,5 plug family
> (1840447/1840489/1840463/1840405/1840382):**
> - **Stripping length 7 mm** (this sheet said 8 mm).
> - **Tightening torque 0.22–0.25 N·m** (M2 screw; this sheet said ~0.5 N·m — over 2×
>   the rated maximum, enough to strip the M2 screw or crack the plug body).
> - **Conductor with INSULATED ferrule: max 0.5 mm²** (this sheet specced 0.75/1.0 mm²
>   insulated ferrules for the 18 AWG J14 leads — they do not meet the plug spec).
>   18 AWG (0.82 mm²) into an MC 1,5 plug must use a **bare stranded end or an
>   UNinsulated ferrule** (rated to 1.5 mm²). The 22 AWG / 0.34 mm² insulated ferrules
>   for J3/J4/J5/J13 are inside the 0.5 mm² limit and stand.
> - These figures apply to every MC 1,5 plug row below (§2.1 steps 3–4, §4 ferrule
>   rows, **and the §4 Tools row — the driver itself must be torque-limited to
>   0.22–0.25 N·m, not a ~0.5 N·m-class blade; scope gap closed 2026-07-21**).
>   MKDS fixed blocks (J2, J6–J11) are a different series — verify their
>   termination data against Phoenix 1715734/1715721 at build; do not reuse either set
>   of numbers across series.
> - Machine-readable copy of the corrected data: `docs/phase8_revD_harness_bom.csv`
>   (H6/H7 release artifact). Original text below is retained with strikethrough-style
>   inline corrections — not silently edited.
>
> **⚠ FIELD CORRECTION 2026-07-24 — LANES 21/22 HAVE NO C.I.S.:**
> Physical inspection found a purely mechanical cushion (shock plus coil-over
> spring), with no cushion-interlock switch or wiring. The replacement DIELL is
> the ball/cycle trigger, not a proved pit-entry safety device. J14.3–4 remains
> OPEN and the field rail cannot arm. The leading J14 candidate is an
> energize-to-prove control-power sensing relay, but that contact only gates board
> permission. If a new pit-entry interlock is required as the final protection,
> it must act in an approved upstream master/control-power safety-disconnect
> architecture; landing it only at J14 cannot stop a welded downstream contact.

**Status: NON-J14 HARNESS BUILDABLE; INSTALLATION NO-GO — Candidate C for J14.1–2 is formal, but J14.3–4 and the lane-21/22 pit-entry-interlock disposition remain OPEN.**
Written 2026-07-07. One lane = one board = one harness. This sheet is for the **pilot lane 21** (SS chassis + Omega-Tek, C1 34-pin + C2A 50-pin AMP edge connectors). Lane 22 is a clone — see the ×2 column in §4 — but **re-verify every machine-side landing on 22's own connectors before crimping** (same chassis type, still per-lane proof).

**Reads-with (do not build without them open):**
- `phase8_machine_harness_spec_sectionF.md` — the governing spec (wire classes, bundles, separation, Path A/B).
- `phase8_interlock_redesign.md` §3-C + §4-RESULTS + §7 — why J_SAFE1-2 is a jumper, and the standing conditions.
- `phase8_trackB_controller_cutover_runbook.md` §3.3/§3.4 + Stage 5/6b + gate G3 — when each machine end lands, and the coil-drop proof.
- `phase8_revB_board1_prepower_test_checklist.md` — pre-power gate before the board ever sees this harness live.

**Mating-strategy decision (per Section F F.3): this sheet builds PATH B** — documented splice / piggyback taps on the **cable-side machine wires** behind C1/C2A. Path A (proper AMP mates) stays blocked on the housing-vs-contact P/N + contact-gender confirm (F.5 step 0 remainder); Section F names Path B the de-risked pilot fallback, and Path B additionally gives the cleanest rollback (pull our leads, re-plug the OEM brain — every tap goes inert). Back-probe pins are a **metering/verification aid only** in this build, never a permanent termination.

**Lead disposition legend:**
- **BUILD** — cut, label, ferrule, terminate board end into the plug NOW; land machine end per this sheet (Stage 5 for taps, per-row otherwise).
- **CUT+LABEL-ONLY** — cut to length, label both ends, ferrule + seat the board end in the plug, **heat-shrink-cap and coil the machine end. DO NOT LAND.** The row names the session that closes it.
- **NO-LEAD** — plug position left empty. Do not stuff a wire "for later."

**Non-negotiables (from Section F + the runbook):**
1. **Never land a sense lead on a common rail** — C2A **J / F / U** (gripper/control common, chassis return) and **N** (motion-cam common) ring to everything.
2. **Never cut or interrupt the existing Stop/control-power path or the SC/TB
   coil ladder for a tap** — bridge/tap in parallel only (Section F F.3 Path-B
   rule). DIELL is a ball/cycle trigger; use only its approved sensor-side
   signal/GND tap and never claim it as pit-entry protection.
3. **The board never sources machine power.** Outputs are dry contacts in series with existing 24 VAC coil circuits. Never feed board 5 V into a C1/C2A cavity.
4. **Bundle separation** (Section F F.2): field-sense (22 AWG) ≥50 mm from safety/output runs (18 AWG); cross at 90°; separate jackets/looms from enclosure to machine.
5. All machine-side work **LOCKED OUT** (runbook §1 mode A) except the explicitly powered mapping/proof steps.

---

## 1. PER-CONNECTOR LEAD TABLES

Label format: print exactly the **Label text** column on heat-shrink at BOTH ends of the lead (board end may add the plug pin, e.g. `J4-8 · GS8 -> C2A-K`). Suggested colors assume discrete UL1007-class hookup wire; if building Bundle 1 as shielded multicore (Belden 1063A / Alpha 5160C — Section F's preferred cable), substitute the cable's core colors and record the actual core color beside each row on the printed sheet.

Lengths: enclosure→C1/C2A run measured ~0.6–1.0 m → **cut sense/output leads at 1.2 m** (service slack + drip loop, per F.2). DIELL leads 1.5 m. Foul 1.0 m. Mask-LED run is **not in Section F — measure on site before cutting** (estimate 2–3 m; treat as an estimate, not a measurement).

### J2 — 5 V logic in (MKDS wire-direct, 3-pos: pin1 = 5 V, pins 2–3 = GND — per the rev netlist `J_PWR`)

| Pin | Signal | AWG | Color | Label text | Termination (far end) | Disposition |
|---|---|---|---|---|---|---|
| J2-1 | +5 V in | 18 | red | `J2-1 +5V <- PSU` | enclosure 5 V PSU + terminal | **BUILD** (0.5 m, enclosure-internal) |
| J2-2 | GND | 18 | black | `J2-2 GND <- PSU` | enclosure PSU − terminal | **BUILD** (0.5 m, enclosure-internal) |
| J2-3 | GND | 18 | black | `J2-3 GND <- PSU` | enclosure PSU − terminal | **BUILD** (0.5 m, enclosure-internal) |

> PSU sized ≥1 A (6 × ~77 mA relay coils + logic — readiness checklist §3). Never also feed 5 V into J1 pin 1.

### J3 — J_FAST_IN (Phoenix MC 1,5/10-ST-3,5 plug, PN **1840447**) — 22 AWG throughout

| Pin | Signal | Color | Label text | Machine-side termination | Disposition |
|---|---|---|---|---|---|
| J3-1 | SA (sweep cam) | orange | `SA -> POWERED MAP ONLY - DO NOT LAND` | none yet — cavity unknown (cold reads invalid: ~21 Ω relay-coil sneak paths, C2A-N is the cam common) | **CUT+LABEL-ONLY** — closes at the **powered cam-cavity mapping at cutover** (runbook §3.2) |
| J3-2 | SB (guard cam) | orange | `SB -> POWERED MAP ONLY - DO NOT LAND` | none yet | **CUT+LABEL-ONLY** — powered cutover mapping |
| J3-3 | SC (interlock cam echo) | orange | `SC -> C2A-U - DO NOT LAND (echo redesign + F.5 step 4)` | **known cavity (C2A-U via the N.O. pink wire) but do NOT land**: U doubles as a live-ladder/common node; front-end class unresolved (Section F F.4 — powered meter, F.5 step 4) and the single-node software-echo redesign (review findings #4/#12) has not consumed the §4.3 window capture | **CUT+LABEL-ONLY** — closes at the powered session (F.5 step 4 + §4.3 capture) + the echo-redesign workstream |
| J3-4 | TA1 (table cam) | orange | `TA1 -> POWERED MAP ONLY - DO NOT LAND` | none yet | **CUT+LABEL-ONLY** — powered cutover mapping |
| J3-5 | TA2 (table cam) | orange | `TA2 -> POWERED MAP ONLY - DO NOT LAND` | none yet | **CUT+LABEL-ONLY** — powered cutover mapping |
| J3-6 | TB | — | — | **nothing to land** — TB has NO standalone cavity on this chassis (both TB wires tie into the SC/U node; measured 2026-06-27) | **NO-LEAD** |
| J3-7 | DIELL-L signal | blue | `DIELL-L SIG (DIELL harness tap)` | IDC tap on the DIELL **L-beam signal wire** on the DIELL harness (NOT C2A). ~16 V rest / 0.7 V beam-broken, NPN active-low. **NEVER tap the sensor's 24 V supply wire.** Twist with J3-9. | **BUILD** (1.5 m) |
| J3-8 | DIELL-R signal | yellow | `DIELL-R SIG (DIELL harness tap)` | IDC tap on the DIELL **R-beam signal wire**; same rules; twist with J3-10 | **BUILD** (1.5 m) |
| J3-9 | FIELD_GND (DIELL-L return) | black | `J3-9 FGND (DIELL GND tap)` | IDC tap on the DIELL harness GND/return wire (signal + GND only per F.2) | **BUILD** (1.5 m, twisted pair w/ J3-7) |
| J3-10 | FIELD_GND (DIELL-R return) | black | `J3-10 FGND (DIELL GND tap)` | IDC tap on the DIELL harness GND/return wire | **BUILD** (1.5 m, twisted pair w/ J3-8) |

> The four motion-cam leads (J3-1/2/4/5) + SC (J3-3) get their board ends seated in the 1840447 plug now so the powered mapping session only has to land machine ends. Cap + coil + tag each machine end.
> **Front-end caveat:** if the powered class check (F.5 step 4) reads sustained 24 VAC at any cam cavity, that channel needs the board's 24 VAC-rectified front-end option populated **before** its lead lands — the lead itself (22 AWG / 300 V insulation) is already rated for it.

### J4 — J_SLOW_IN_A (Phoenix MC 1,5/14-ST-3,5 plug, PN **1840489**) — 22 AWG throughout

All gripper cavities ✓ measured (2026-06-27 + GS8 2026-07-07). Gripper return = **machine chassis** (no TAC strip on this cabinet). Polarity locked: gripped (pin present) = CLOSED to chassis.

| Pin | Signal | Color | Label text | Machine-side termination | Disposition |
|---|---|---|---|---|---|
| J4-1 | GS1 | white | `GS1 -> C2A-C` | IDC tap on the cable-side wire entering C2A cavity **C** (verify: beep tap point → cavity contact face, brain unplugged) | **BUILD** |
| J4-2 | GS2 | white | `GS2 -> C2A-H` | IDC tap, C2A cavity **H** wire | **BUILD** |
| J4-3 | GS3 | white | `GS3 -> C2A-M` | IDC tap, C2A cavity **M** wire | **BUILD** |
| J4-4 | GS4 | white | `GS4 -> C2A-S` | IDC tap, C2A cavity **S** wire | **BUILD** |
| J4-5 | GS5 | white | `GS5 -> C2A-W` | IDC tap, C2A cavity **W** wire | **BUILD** |
| J4-6 | GS6 | white | `GS6 -> C2A-a` | IDC tap, C2A cavity **a** (lower-case) wire | **BUILD** |
| J4-7 | GS7 | white | `GS7 -> C2A-e` | IDC tap, C2A cavity **e** (lower-case) wire | **BUILD** |
| J4-8 | GS8 | white | `GS8 -> C2A-K` | IDC tap, C2A cavity **K** wire (✓ measured 2026-07-07; the old 48H prediction was WRONG — H is GS2) | **BUILD** — then the **G2-GS8 drop-one-pin proof at cutover is mandatory** (unlanded GS8 reads "not standing" → pin-8-only leave = false STRIKE) |
| J4-9 | GS9 | white | `GS9 -> C2A-r` | IDC tap, C2A cavity **r** (lower-case) wire | **BUILD** |
| J4-10 | GS10 | white | `GS10 -> C2A-v` | IDC tap, C2A cavity **v** (lower-case) wire | **BUILD** |
| J4-11 | GP | orange | `GP -> C2A-?? DO NOT LAND (predicted 412DD, unmeasured)` | none yet — prediction only, not resolved by the 2026-06/07 metering | **CUT+LABEL-ONLY** — closes at the next cold probe session / cutover Stage 2 (runbook §3, B.5) |
| J4-12 | OS ⊕ | — | — | cavity UNKNOWN, channel unused by the FSM | **NO-LEAD** (spare) |
| J4-13 | BS | white | `BS -> C2A-CC` | IDC tap, C2A cavity **CC** wire (bin switch) | **BUILD** |
| J4-14 | FIELD_GND | green | `J4-14 FGND -> CHASSIS` | **ring lug on a paint-free chassis stud** + star washer (the gripper return IS the chassis — measured; do NOT go looking for a TAC strip) | **BUILD** |

> **GS-map rule (gate G2-GSMAP):** the GS-label→J4-pin binding is FIXED in `controller_io.py` (`IN_A_MAP`; drift-guard asserted). Lane-specific assignment lives **in this harness crimp order** — J4 lead *N* → measured cavity of gripper *N*, exactly as tabled above. Never "fix" a swap in software; re-crimp the lead. Verify by the per-gripper drop-one-pin test at cutover (runbook §3.1).

### J5 — J_SLOW_IN_B (Phoenix MC 1,5/12-ST-3,5 plug, PN **1840463**) — 22 AWG throughout

| Pin | Signal | Color | Label text | Machine-side termination | Disposition |
|---|---|---|---|---|---|
| J5-1 | PBZ | white | `PBZ -> C2A-EE` | IDC tap, C2A cavity **EE** wire (zero/manual-intervention pushbutton; shorts to common U when pressed — ✓ measured) | **BUILD** |
| J5-2 | PBC ⊕ | orange | `PBC -> C2A-?? DO NOT LAND (unmeasured)` | none yet — "EE area" is approximate only. It's a dry momentary → cold-probeable: press + beep candidate cavity → U | **CUT+LABEL-ONLY** — closes at the next cold probe / cutover Stage 2 (B.5) |
| J5-3 | FOUL | orange | `FOUL -> ?? DO NOT LAND (F.5 step 6 - lamp wire unmetered)` | none yet — Radaray harness tap is marginal (~5 V, 0.3 V swing); preferred lamp-wire tap unmetered, possibly AC (front-end class open) | **CUT+LABEL-ONLY** (1.0 m) — closes at F.5 step 6 (meter the foul lamp wire, powered session) |
| J5-4 | TENTH ⊕ | — | — | cavity UNKNOWN | **NO-LEAD** (spare) |
| J5-5 | MAN_T ⊕ | — | — | descriptive code only ("T-2"), unmeasured | **NO-LEAD** (spare) |
| J5-6 | MAN_S ⊕ | — | — | descriptive only | **NO-LEAD** (spare) |
| J5-7 | MAN_SWS ⊕ | — | — | descriptive only | **NO-LEAD** (spare) |
| J5-8 | MAN_SWSR ⊕ | — | — | UNKNOWN | **NO-LEAD** (spare) |
| J5-9/10/11 | AUX1–3 | — | — | unallocated | **NO-LEAD** (spare) |
| J5-12 | FIELD_GND | green | `J5-12 FGND -> CHASSIS` | ring lug, same chassis stud as J4-14 (second lug or stacked w/ star washers) | **BUILD** |

### J6–J11 — J_MOTION outputs (MKDS 1,5/2-5,08 wire-direct; **pin 1 = NO, pin 2 = COM** on every block) — 18 AWG throughout, Bundle 3

Every output = an isolated dry contact inserted **in series with an existing 24 VAC coil circuit**. Cavities below are bench/at-machine measured continuity groups; the exact pair to bridge inside each group is the **runbook §3.3 land-check** at cutover Stage 2. Build all 12 leads now (Section F: "the output side can be cabled now"); machine ends land at Stage 5. Full insertion method + candidate-C caveat: **§3 of this sheet.**

| Conn | Signal | Pin/lead | Color | Label text | Machine-side termination (at Stage 5, after §3.3 confirm) | Disposition |
|---|---|---|---|---|---|---|
| J6 | S — sweep | 1 (NO) | red | `S NO -> C1{C,D,N,T} feed side` | tap on the feed-side wire of the confirmed pair within C1 {C,D,N,T} | **BUILD** — land per §3, **candidate-C caveat applies** |
| J6 | | 2 (COM) | black | `S COM -> C1{C,D,N,T} coil side` | tap on the coil-side wire (beeps to the S-contactor coil A1/A2, ~5 Ω Siemens) | **BUILD** |
| J7 | T — table | 1 (NO) | red | `T NO -> C1{A,K,H,E,+L} feed side` | tap on the feed-side wire of the confirmed pair within C1 {A,K,H,E,+L through-coil} | **BUILD** — **candidate-C caveat applies** |
| J7 | | 2 (COM) | black | `T COM -> C1{A,K,H,E,+L} coil side` | tap on the coil-side wire (beeps to the T-contactor coil, 24 VAC — measured 2026-07-07) | **BUILD** |
| J8 | SP — spot | 1 (NO) | red | `SP NO -> C2A (spot sol feed)` | tap per §3.3 confirm (C2A direct, 0 Ω group; 100 Ω solenoid coil) | **BUILD** |
| J8 | | 2 (COM) | black | `SP COM -> C2A (spot sol coil)` | tap per §3.3 confirm | **BUILD** |
| J9 | BE ⊕ — back-end | 1 (NO) | red | `BE NO -> C1{KK,C,L} feed side` | tap per §3.3 confirm — circuit straddles C1 (KK, C, L) + coil tap FF@66 Ω + C2A | **BUILD** |
| J9 | | 2 (COM) | black | `BE COM -> BE coil side (FF@66R)` | tap per §3.3 confirm | **BUILD** |
| J10 | M ⊕ — master | 1 (NO) | red | `M NO -> C2A{FF,U,B} feed side` | tap per §3.3 confirm (80 Ω 82-70-5515 relay) | **BUILD** |
| J10 | | 2 (COM) | black | `M COM -> C2A{FF,U,B} coil side` | tap per §3.3 confirm | **BUILD** |
| J11 | M2 ⊕ — sweep-reverse | 1 (NO) | red | `M2 NO -> C2A (swp-rev feed)` | tap per §3.3 confirm — **preserve the Expander interlock / shorting-plug function, not just the cavity** | **BUILD** |
| J11 | | 2 (COM) | black | `M2 COM -> C2A (swp-rev coil)` | tap per §3.3 confirm | **BUILD** |
| J12 | M1 — ball-return | — | — | — | **DNP on the board, never metered** — confirm existence per runbook §3.6 before any future populate | **NO-LEAD** |

### J13 — J_LAMP_LED (Phoenix MC 1,5/6-ST-3,5 plug, PN **1840405**) — 22 AWG; our LEDs in the mask housings (machine 15 VDC mask supply abandoned — leave OEM mask wiring intact, lift don't cut)

Pin order per the rev netlist (`lamp_order`): pin1 = VCC_5V, pin2 = GND, pins 3–6 = L_FIRST / L_SECOND / L_STRIKE / L_FOUL returns (LED anodes → pin1 rail; cathodes → their return pin; drive/limit is on-board).

| Pin | Signal | Color | Label text | Machine-side termination | Disposition |
|---|---|---|---|---|---|
| J13-1 | VCC_5V (LED anode rail) | red | `J13-1 5V -> MASK LED ANODES` | daisy-chain to all 4 LED anodes in the mask housings (Stage 3). **LED-end termination method: solder to the LED pigtail, adhesive heat-shrink over the joint** (no crimps in the mask housing — vibration) | **BUILD** board end now; terminate LED end at cutover Stage 3. **Length: measure the mask run on site (est. 2–3 m — estimate, confirm)** |
| J13-2 | GND | black | `J13-2 GND (reserve)` | none — logic GND; do **NOT** tie to chassis or FIELD_GND at the mask | **CUT+LABEL-ONLY** (length = the on-site mask-run measurement, same as J13-1/3–6; reserve — land only if the LED install needs a logic return) |
| J13-3 | L_FIRST return | white | `L_FIRST <- mask LED cathode` | 1st-ball LED cathode | **BUILD** (board end now, LED end Stage 3) |
| J13-4 | L_SECOND return | white | `L_SECOND <- mask LED cathode` | 2nd-ball LED cathode | **BUILD** |
| J13-5 | L_STRIKE return | white | `L_STRIKE <- mask LED cathode` | strike LED cathode | **BUILD** |
| J13-6 | L_FOUL return | white | `L_FOUL <- mask LED cathode` | foul LED cathode | **BUILD** |

> Before crimping the LED ends, re-check pin→lamp order against the board silk / `generate_kicad_netlist_revB.py` `lamp_order` — a swap is a re-label + re-land, cheap now, confusing at soak.

### J14 — J_SAFETY (Phoenix MC 1,5/4-ST-3,5 plug, PN **1840382**) — 18 AWG (Bundle 2 class)

Loop topology on-board: VCC5 → **pins 1–2 (TBSC source position)** →
**pins 3–4 (legacy Stop/CIS source position; future approved
Stop/control-power interface)** → PMOS → RELAY_ENABLE_RAIL. Both source
positions must be closed for the rail to arm.

| Pin(s) | Signal | AWG | Color | Label text | Termination | Disposition |
|---|---|---|---|---|---|---|
| J14-1 ↔ J14-2 | TBSC loop | 18 | yellow | see §2 — verbatim label | **the Candidate-C engineered jumper — bridge inside the plug, no machine side.** Full construction in **§2**. | **BUILD (as the §2 jumper)** |
| J14-3 | Stop/control-power source (out) | 18 | yellow | `J14-3 STOP/CTRL-PWR - OPEN - DO NOT LAND OR JUMPER` | none — landing **OPEN**, see §2.3 | **CUT+LABEL-ONLY** (1.2 m) |
| J14-4 | Stop/control-power source (return) | 18 | yellow | `J14-4 STOP/CTRL-PWR - OPEN - DO NOT LAND OR JUMPER` | none — landing **OPEN**, see §2.3 | **CUT+LABEL-ONLY** (1.2 m) |

---

## 2. THE J_SAFE JUMPER PLUG (Candidate C — engineered part)

### 2.1 Construction

1. Take **one Phoenix MC 1,5/4-ST-3,5 plug (PN 1840382)** — this IS the lane's J14 harness plug (positions 3–4 carry the Stop/control-power cut+label leads from the table above; the jumper lives on positions 1–2 of the same plug).
2. Cut **~120 mm of 18 AWG stranded, yellow** (600 V insulation — Bundle 2 spec). Form a U.
3. Strip both ends ~~8 mm~~ **7 mm (corrected 2026-07-21, H7)**; ~~fit 0.75/1.0 mm²
   ferrules~~ **leave bare stranded or fit UNinsulated ferrules — insulated ferrules
   above 0.5 mm² do not meet the MC 1,5 plug spec (corrected 2026-07-21, H7)**.
4. Terminate one end in **position 1**, the other in **position 2**. Torque ~~0.5 Nm~~
   **0.22–0.25 N·m (corrected 2026-07-21, H7 — 0.5 N·m is over 2× the M2 screw rating)**
   (small flat-blade), tug-test both ends.
5. Slide a printed heat-shrink flag onto the U **before** the second crimp, with this label text, verbatim:

   > **`TBSC JUMPER - ENGINEERED PART (Candidate C, DECIDED 2026-07-07). TB/SC collision protection is DELEGATED to the OEM 24VAC ladder (SC+TB parallel closed-when-SAFE contacts in the S/T coil circuits - proven at machine 2026-07-07). NOT a bypass: the per-lane Stage-6b/G3 coil-drop proof is REQUIRED before live motion, every cutover. See docs/phase8_interlock_redesign.md §7.`**

   If the printer can't fit it, the flag carries the first sentence + `see phase8_interlock_redesign.md §7`, and the full text goes on the wire-map card taped inside the enclosure door (mandatory either way).
6. Label the plug body: **`J14 J_SAFETY · 1-2 = TBSC jumper (engineered) · 3-4 = STOP/CTRL-PWR (OPEN - never jumper)`**.

### 2.2 What this jumper is — and is not

- It closes the board's TBSC rail condition **permanently**, because as measured (2026-06-27) **no isolatable dry NC pair exists on this chassis** — SC is reachable only on its N.O. wire at a live-ladder/common node, TB never isolates. The rail's TB/SC condition is **formally delegated to the OEM ladder**: SC+TB are a **parallel closed-when-SAFE pair**; danger = **both cam levers BACK (buttons released)** = coil circuit dies even on a manual command — proven for both S and T at the machine 2026-07-07 (`phase8_interlock_redesign.md` §4-RESULTS).
- The delegation is only real **if the board's S/T contacts land in series with those same coil circuits** (§3-C insertion-point caveat). That is why the **Stage-6b/G3 coil-drop proof is a hard gate on every lane, every cutover**: with the board commanding S (then T), body clear, force both levers BACK → **the coil must die even with the board contact closed**. A jumpered J14-1/2 with a failed or skipped coil-drop proof = **G3 automatic FAIL → abort + rollback**.
- **Any other J_SAFE jumper remains FORBIDDEN** (runbook Stage 6b): this documented part on 1-2 is the sole exception. Never bridge 1→4 (skips the future Stop/control-power condition); never jumper 3-4 at the machine.

### 2.3 J_SAFE3-4 (legacy Stop/CIS source position) — status per Section F: **OPEN**

Physical inspection on 2026-07-24 found **no C.I.S. device or wiring on lanes
21/22**. The cushion is mechanical, and DIELL replaced the old cushion-start
ball trigger. Whether another pit-entry interlock exists remains unresolved.
There is no approved J14 dry interface, so the landing is **OPEN** and this
sheet builds only the two cut+label leads.

- **Leading J14 interface:** an approved, galvanically isolated,
  energize-to-prove control-power sensing relay: a correctly rated 24 VAC coil
  across the selected downstream control rail, with its N.O. volt-free contact
  on J14-3/4. Control-power loss, Stop demand, breaker opening, relay-coil failure,
  tap open-wire, or plug removal then opens the board source position for the
  de-energize-to-open failure modes. A welded sensing contact remains credible;
  the proof procedure must deliberately de-energize the coil and verify
  J14.3–4/TP16 open. Exact rail, relay, enclosure, protection, wiring,
  and acceptance limits require a qualified drawing and guarded powered test.
  The manifest-controlled proof interval is **365 days maximum**, with an
  earlier repeat after relevant safety/control electrical service; expired
  evidence blocks healthy monitor status.
- **Pit-entry decision:** determine whether another installed pit-entry
  interlock exists. If none exists, the owner and a qualified machine-safety
  reviewer must either install an approved upstream pit-entry safety disconnect
  or formally accept the existing Stop-plus-lockout-only operating design before
  cutover. A new switch placed only at J14 is diagnostic/permission gating and
  **cannot** serve as the final disconnect for a welded downstream contact.
- **Hard consequence:** the rail **cannot arm** until J14-3/4 closes through the
  approved interface — that is deliberate. The bench jumper on 3-4 (readiness
  checklist §3) is a **bench-only tool: remove before cutover.** FA-13/G3 must
  prove Stop→master/control-power→TP16 drop, every interface open-wire/failure,
  and any installed/new upstream pit interlock separately. C.I.S. is recorded
  absent/N/A on lanes 21/22, never silently passed.

---

## 3. OUTPUT-SIDE SERIES INSERTION (per motion channel) — cutover Stage 5, per runbook §3.3

### 3.1 The method (all six channels)

With the OEM brain **unplugged (Stage 4), the brain's own switching element IS the series break** in each coil circuit — the circuit dead-ends at two C1/C2A cavities the brain used to bridge. The board contact re-completes that path:

1. **Confirm the group (Stage 2, §3.3, LOCKED OUT):** beep-verify the measured cavity group for the channel (table in §1). Then identify the two sides of the brain's gap: the **coil side** beeps at coil resistance to the load (S: Siemens contactor A1/A2 ~5 Ω · T: heavy-lug contactor, 24 VAC coil · SP: 100 Ω · BE: 66 Ω @ FF · M/M2: 80 Ω). The **feed side** runs toward the 24 VAC transformer/ladder — cold reads on that side can show ohms through relay-coil sneak paths, so if feed-side identity is ambiguous cold, mark it provisional and let the Stage-7 first-motion test (single deliberate command, hand on the breaker) be the arbiter.
2. **Tap, don't cut:** IDC tap (rated for the machine wire gauge and ≥ coil inrush — S is a 5 Ω coil, real inrush; use 18–14 AWG-class taps, not telecom Scotchloks, on S/T) on the **cable-side wire** of each of the two cavities: **NO lead (pin 1) → feed-side wire · COM lead (pin 2) → coil-side wire.** (The contact is non-polar; NO→feed is convention for the wire-map card.) If a tap can't make a sound joint on the machine wire, fall back to cut-and-Wago 221 — and pre-stage the labeled 18 AWG **rollback bridge jumper** for that channel (rollback = pull board leads from the Wagos, insert the bridge, re-plug the brain).
3. **Tug-test + meter each tap** (<0.5 Ω tap-to-wire), photograph, log on the wire-map card.
4. **Rollback property (why taps, not cuts):** with taps, pulling the board leads (or just unscrewing the MKDS plugs... they're wire-direct — pull the leads from the taps) and re-plugging the OEM brain restores the machine **exactly** — the taps go inert. ⚠️ Never re-plug the brain while the board leads are still landed AND the rail can arm — two controllers in parallel is forbidden; rollback order is: rail down/board depowered → lift board leads → re-plug brain.

### 3.2 ⚠️ THE CANDIDATE-C CAVEAT — S (J6) and T (J7) specifically

The whole Candidate-C decision rests on the OEM SC/TB **parallel closed-when-SAFE contacts staying electrically in series with the coil path the board completes.** Therefore, on S and T:

- **Bridge ONLY the brain's gap.** Never tap "conveniently" from the transformer/feed rail upstream of the ladder — if the board's feed-side tap lands upstream of the SC/TB contacts, the board bypasses the machine's own collision protection and Candidate C is void **for that lane**.
- The §4-RESULTS proof (2026-07-07) used the **rear-panel manual switches** — it proves the ladder blocks the *manual* path. Whether it blocks the **board's** path depends entirely on where these two taps land. That is only provable live:
- **Stage-6b/G3 coil-drop gate (hard, per lane, every cutover):** body clear, board commands **S** → hold both SC/TB levers **BACK** (the danger state) → **S-contactor coil must read 0 VAC even with the board contact closed.** Repeat for **T**. Coil energizes in the danger state = the insertion bypassed the interlock → **lift the feed-side tap immediately, re-select the tap point, re-prove. No live motion until both channels pass.** (Runbook Stage 6b / gate G3; `phase8_interlock_redesign.md` §7 standing conditions.)

### 3.3 Channel notes

- **S (J6):** group C1 {C, D, N, T}. Highest inrush (5 Ω coil) — best joints here; snubber/MOV across the board contact stays DNP until coil current is characterized (F.5 step 7 / F.6 #10), so avoid rapid-cycling S during tests.
- **T (J7):** group C1 {A, K, H, E, +L through-coil}. The L cavity reads *through* the coil — don't pick L as the coil-side tap; tap the direct coil-side wire (beep to A1/A2 confirms).
- **SP (J8):** C2A direct (0 Ω group), 100 Ω solenoid — momentary duty only.
- **BE (J9):** straddles C1 (KK, C, L) + coil tap FF@66 Ω + C2A — the §3.3 confirm must sort which side of the straddle is feed vs coil before tapping. Continuous-duty load.
- **M (J10):** C2A {FF, U, B}. **U is a common rail** — expect it to be the common/return side, and never treat a U tap as the switched feed without beeping it out.
- **M2 (J11):** C2A direct — **preserve the Expander-card interlock / shorting-plug function**: confirm the sweep-reverse path still behaves with the Expander removed/bypassed per the §3.3 land-check before trusting M2.
- **M1 (J12):** DNP, no lead, not harnessed — existence check per §3.6 is a future item.

---

## 4. MATERIALS BOM — one lane (+ ×2 column for 21+22)

Plugs per `phase8_revC_readiness_checklist.md` §3 (the BOM-gap list — these ship separately from the boards).

| Item | Spec / PN | Qty ×1 lane | Qty ×2 (21+22) |
|---|---|---|---|
| Plug, J3 J_FAST_IN | Phoenix MC 1,5/10-ST-3,5 · **1840447** | 1 | 2 |
| Plug, J4 J_SLOW_IN_A | Phoenix MC 1,5/14-ST-3,5 · **1840489** | 1 | 2 |
| Plug, J5 J_SLOW_IN_B | Phoenix MC 1,5/12-ST-3,5 · **1840463** | 1 | 2 |
| Plug, J13 J_LAMP_LED | Phoenix MC 1,5/6-ST-3,5 · **1840405** | 1 | 2 |
| Plug, J14 J_SAFETY (+ §2 jumper) | Phoenix MC 1,5/4-ST-3,5 · **1840382** | 1 (+1 spare) | 2 (+2 spare) |
| Wire 22 AWG, white (sense, build-now) | UL1007-class stranded, 300 V | ~25 m | ~50 m |
| Wire 22 AWG, orange (CUT+LABEL-ONLY leads) | same — orange = "do not land" convention | ~12 m | ~24 m |
| Wire 22 AWG, green (FIELD_GND) | same | ~3 m | ~6 m |
| Wire 22 AWG, black (DIELL GND, J13 GND) | same | ~6 m | ~12 m |
| Wire 22 AWG, blue + yellow (DIELL L/R sig) | same, 1.5 m each + spare | ~4 m | ~8 m |
| Wire 22 AWG, red (J13 LED 5 V rail) | same — mask-run length site-measured | ~4 m (est) | ~8 m |
| *(alternative to the six rows above)* Bundle-1 multicore | **Belden 1063A** (12×22 AWG, foil+drain) or Alpha 5160C — Section F preferred; J4's 12 build-now leads (GS1–10 + BS + FGND) fit one run exactly | 1 × ~1.5 m run (+ discrete for J3/J5/J13) | 2 runs |
| Wire 18 AWG, red (output NO leads) | stranded, 600 V | ~8 m | ~16 m |
| Wire 18 AWG, black (output COM leads) | same | ~8 m | ~16 m |
| Wire 18 AWG, yellow (J14 jumper + Stop/control-power + rollback bridges) | same | ~5 m | ~10 m |
| *(alternative)* Bundle-3 multipair | **Belden 1419A** (6-pair 18 AWG) per F.2 | 1 × 1.2 m run | 2 |
| Ferrules 0.34 mm² (22 AWG) | insulated, for MC 1,5 plugs (≤ 0.5 mm² insulated limit ✓) | ~45 (buy 100-pk) | ~90 (1 pk) |
| Ferrules 0.75–1.0 mm² (18 AWG) | ~~insulated, for MKDS + J14~~ **CORRECTED 2026-07-21 (H7): insulated 0.75–1.0 mm² for MKDS blocks ONLY (J2, J6–J11 — verify vs Phoenix 1715734/1715721 data at build). The J14 MC 1,5 positions take UNinsulated 0.75–1.0 mm² ferrules or bare stranded — insulated ferrules above 0.5 mm² do not meet the MC 1,5 spec** | **~31** (J2 ×3 + J6–J11 board ends ×12 + rollback bridges 6×2 insulated; J14 ×4 UNinsulated) — buy 100-pk of each | ~62 (1 pk each) |
| IDC taps, small-gauge (sense) | 3M Scotchlok IDC class, sized to the machine sense-wire gauge (verify on site) | 16 used → buy 30 | 60 |
| IDC taps, 18–14 AWG class (outputs) | T-tap / Scotchlok rated ≥10 A — S/T coil inrush | 12 used → buy 20 | 40 |
| Wago 221-413 (3-port lever nuts) | fallback splice + output cut-fallback | 12 | 24 |
| Rollback bridge jumpers | 18 AWG yellow, 0.2 m, ferruled both ends, labeled `ROLLBACK BRIDGE <chan>` — pre-make one per output channel | 6 | 12 |
| Ring lugs + star washers | sized to the chosen chassis stud (measure on site) | 2 lugs + washers | 4 |
| Heat-shrink label stock | printable 3:1, white — **~100 labels/lane** (≈50 leads × 2 ends + plug bodies) | **2 m** | **4 m** |
| Heat-shrink end caps | for CUT+LABEL-ONLY machine ends (J3-1..5, J4-11, J5-2, J5-3, J13-2, J14-3, J14-4 = 11) | **~12** | ~24 |
| Split loom / jacket | ~10 mm, keep Bundle 1 and Bundle 3 in **separate** looms (≥50 mm apart) | ~4 m | ~8 m |
| Wire-map card | printed §1 tables + §2.1 full label text, taped inside enclosure door | 1 | 2 |
| Back-probe pin set | metering aid ONLY (never permanent termination in this Path-B build) | 1 set | 1 set |
| Tools | ferrule crimper 0.25–2.5 mm², ~~small flat-blade (~0.5 Nm)~~ **torque-limiting driver set to 0.22–0.25 N·m with a small flat blade (corrected 2026-07-21, H7 — a ~0.5 N·m-class driver is twice the MC 1,5 M2 screw rating; if no torque driver is on hand, use a plain small flat-blade and stop at snug + 1/8 turn, then tug-test)**, strippers 22/18 AWG, pliers for IDC taps, DMM, label printer | on hand | — |

**Path-A note:** no AMP mating housings/contacts in this BOM — Path A stays blocked on the housing-vs-contact P/N + gender confirm (Section F F.3 / F.5 step 0). If Path A unblocks before fleet rollout, the machine-side taps get superseded by proper 34/50-pos mates; this pilot ships on taps.

---

## 5. BUILD ORDER + QA

### 5.1 Bench build (at home, before any machine visit)

1. Print the §1 tables + §2.1 label text = the **wire-map card**. Print all heat-shrink labels first — **label before you crimp.**
2. Cut all leads to length per §1 — **EXCEPT the J13 mask leads (J13-1 through J13-6): their run must be MEASURED ON SITE first (§1 note), so defer those cuts to the first machine visit.** Slide labels on. Twist the DIELL pairs (J3-7+9, J3-8+10).
3. Ferrule + terminate every **board end** into its plug (J3/J4/J5/J13/J14) or leave ferruled-loose for the wire-direct blocks (J2, J6–J11 — those screw down at enclosure install). Plug orientation: pin 1 per the Phoenix numbering molded on the plug — double-check against the board silk before seating.
4. Build the **§2 jumper plug** (J14-1↔2) exactly per §2.1.
5. **CUT+LABEL-ONLY leads:** heat-shrink-cap the machine end, coil, tape, tag. Orange insulation = never landed without a named session closing it.
6. **Bench continuity pass (before the machine visit):** for every lead, beep plug-pin ↔ far-end conductor; then check **adjacent-pin isolation** on every populated plug (no strand whiskers): J3 1↔2↔3…, J4 1↔2…, J5, J13, J14 (expect 1↔2 SHORT — that's the jumper — and 3↔4 OPEN).

### 5.2 Machine-side landing (LOCKED OUT — runbook §1 mode A; Stage 2 confirms + Stage 5 landing)

Order: **chassis lugs → J4 sense taps → J5 → DIELL taps → outputs → J14.** Photograph every tap. Log every landing on the wire-map card.

1. Master breaker OFF, tagged, **verify 0 V** on the coil circuits (they hold charge — wait 30 s).
2. Land J4-14 + J5-12 ring lugs on a paint-free chassis stud; star washer; tug-test.
3. Per sense tap: identify the cavity's cable-side wire (count at the wire-entry face, **verify by beep to the cavity contact face** — brain side unplugged/isolated), tap ~50–80 mm behind the connector shell, beep tap↔cavity face, tug-test.
4. DIELL: identify signal vs supply on the DIELL harness **by voltage class from prior measurement (~16 V rest on signal) before tapping — never tap the 24 V supply wire.**
5. Outputs per §3 (Stage 5, after the §3.3 Stage-2 confirm).
6. J14: seat the plug (jumper already in it); Stop/control-power leads stay capped (OPEN — §2.3).

### 5.3 Per-lead continuity checklist (board plug pin → machine point) — run complete after landing

| ☐ | Lead | From | To | Expect |
|---|---|---|---|---|
| ☐ | GS1 | J4-1 | C2A cavity **C** contact face | <1 Ω |
| ☐ | GS2 | J4-2 | C2A **H** | <1 Ω |
| ☐ | GS3 | J4-3 | C2A **M** | <1 Ω |
| ☐ | GS4 | J4-4 | C2A **S** | <1 Ω |
| ☐ | GS5 | J4-5 | C2A **W** | <1 Ω |
| ☐ | GS6 | J4-6 | C2A **a** | <1 Ω |
| ☐ | GS7 | J4-7 | C2A **e** | <1 Ω |
| ☐ | GS8 | J4-8 | C2A **K** | <1 Ω |
| ☐ | GS9 | J4-9 | C2A **r** | <1 Ω |
| ☐ | GS10 | J4-10 | C2A **v** | <1 Ω |
| ☐ | BS | J4-13 | C2A **CC** | <1 Ω |
| ☐ | FGND | J4-14 | chassis stud | <1 Ω |
| ☐ | FGND | J5-12 | chassis stud | <1 Ω |
| ☐ | PBZ | J5-1 | C2A **EE** | <1 Ω; pressed → beeps to U/chassis |
| ☐ | DIELL-L | J3-7 | DIELL L signal tap | <1 Ω |
| ☐ | DIELL-R | J3-8 | DIELL R signal tap | <1 Ω |
| ☐ | DIELL GND | J3-9/10 | DIELL harness GND | <1 Ω |
| ☐ | S NO/COM | J6-1 / J6-2 | confirmed C1 feed/coil wires | <1 Ω each; J6-1↔J6-2 OPEN (relay unpowered) |
| ☐ | T NO/COM | J7-1 / J7-2 | confirmed C1 feed/coil wires | <1 Ω each; OPEN across |
| ☐ | SP NO/COM | J8-1 / J8-2 | confirmed C2A wires | <1 Ω each; OPEN across |
| ☐ | BE NO/COM | J9-1 / J9-2 | confirmed straddle wires | <1 Ω each; OPEN across |
| ☐ | M NO/COM | J10-1 / J10-2 | confirmed C2A wires | <1 Ω each; OPEN across |
| ☐ | M2 NO/COM | J11-1 / J11-2 | confirmed C2A wires | <1 Ω each; OPEN across |
| ☐ | TBSC jumper | J14-1 | J14-2 | <1 Ω (the §2 part, labeled) |
| ☐ | Stop/control-power | J14-3 ↔ J14-4 | — | OPEN (nothing landed, no jumper) |
| ☐ | Mask LED rail + 4 returns | J13-1,3,4,5,6 | mask LED pigtails (Stage 3) | <1 Ω each |
| ☐ | DIELL-L return | J3-9 | DIELL harness GND tap | <1 Ω |
| ☐ | DIELL-R return | J3-10 | DIELL harness GND tap | <1 Ω |
| ☐ | 5 V feed | J2-1 | PSU + terminal | <1 Ω |
| ☐ | PSU returns | J2-2 / J2-3 | PSU − terminal | <1 Ω each |

### 5.4 Isolation checks (Section F domains) — board plugs PULLED from the board, harness landed

| ☐ | Check | Expect |
|---|---|---|
| ☐ | FIELD_GND (J4-14 lead) ↔ chassis | **SHORT** (by design — the gripper return IS the chassis) |
| ☐ | Logic GND (J2-2) ↔ chassis | **OPEN** — logic never touches chassis through the harness |
| ☐ | Logic GND (J2-2) ↔ FIELD_GND (J4-14) | **OPEN** in the harness (isolation lives on-board in the TMA-0505S wetting supply — the harness must not defeat it) |
| ☐ | Bundle-1 shield drain (if multicore used) ↔ chassis | **OPEN** — drain terminates to **logic GND at the ENCLOSURE end only**, never grounded at the machine (F.2) |
| ☐ | Every output lead (J6–J11) ↔ chassis and ↔ FIELD_GND | ↔ FIELD_GND: **OPEN**. ↔ chassis: **OPEN or through-coil ohms** — a coil-side tap legitimately reads **~5–100 Ω to chassis through its 24 VAC coil** if the coil common is chassis-referenced (C2A-U in M's group IS the chassis-referenced control common). **Record the value per channel; only a DEAD SHORT (<1 Ω) to chassis is a FAIL** (that means you tapped a common/feed, not the switched coil wire) |
| ☐ | Every sense lead ↔ every output lead | **OPEN** (no cross-bundle contact) |
| ☐ | With machine LOCKED OUT: 0 VAC/VDC on every landed sense tap ↔ FIELD_GND | 0 V before the board is ever connected |

### 5.5 Pre-power + gates

1. Run **`phase8_revB_board1_prepower_test_checklist.md`** on the board + spec §12.9 bench sequence before the harness ever meets a powered machine.
2. Cutover follows the runbook run-of-show: Stage 6 logic-only (rail disabled) input verification — lift one pin per gripper and watch the GS channel flip (**G2-GS8 / G2-GSMAP**), PBZ press, DIELL beam break.
3. **Stage 6b/G3 including the Candidate-C coil-drop proof (§3.2 of this
   sheet) — hard gate, both S and T, before any commanded motion.** Every
   implemented rail condition must independently drop motion permission. The
   §2.3 interface must be complete, Stop must drop master/control power and
   TP16, the pit-interlock disposition must be approved, and every actually
   installed/new upstream pit interlock must pass its own demand test.
4. Powered mapping session items that then close the CUT+LABEL-ONLY leads: cam cavities SA/SB/TA1/TA2 + SC front-end class (F.5 step 4) + §4.3 window-angle capture + foul lamp wire (F.5 step 6) + GP/PBC cold confirms.

---

**Change log:** 2026-07-07 — created (Candidate-C decision formal, `phase8_interlock_redesign.md` §7). Measured values only from the 2026-06-01 bench + 2026-06-27 + 2026-07-07 at-machine sessions; everything unmeasured is CUT+LABEL-ONLY / NO-LEAD / OPEN with its closing session named.
2026-07-21 — **H7 correction (Codex NO-GO audit):** MC 1,5 termination data corrected throughout (strip 7 mm not 8; torque 0.22–0.25 N·m not 0.5; insulated ferrules capped at 0.5 mm² — J14 18 AWG leads go bare/uninsulated). Header banner + inline strikethroughs; machine-readable data in `docs/phase8_revD_harness_bom.csv`. A rev-D lane build additionally carries J15/J16 plugs + CP-MSTB coding (profile in the PLUG, never a standard header; sacrificial-pair proof FA-8) — see `docs/phase8_revD_first_article_pack.md`.
2026-07-24 — **field correction:** lanes 21/22 have no C.I.S. device or wiring;
DIELL is the ball/cycle trigger. J14.3–4 remains open pending the approved
Stop/control-power interface and pit-entry-interlock disposition. A J14-only
switch is not accepted as the final pit safety disconnect.
2026-07-21 (later) — **H7 scope gap closed (post-remediation review):** the §4 Tools row still specified a "small flat-blade (~0.5 Nm)" driver — a tool characterized at 2× the corrected torque limit, missed because the banner's scope list skipped the Tools row. Tools row now calls for a torque-limiting driver set to 0.22–0.25 N·m (fallback: plain blade, snug + 1/8 turn + tug-test); banner scope list updated.

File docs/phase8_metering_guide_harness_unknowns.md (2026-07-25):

# Metering Guide — Closing the Section F Harness Unknowns (REVISED)

**Most of the bench work is already done** (2026-06-01 spare-cabinet session). This revision marks what's confirmed and foregrounds the short list that actually remains — which is essentially **"trace the C2A input cavities at the machine."**

---

## ✅ Already CONFIRMED (2026-06-01 bench) — do NOT re-measure

- **Connectors ID'd, P/N read:** AMP **67209 / 67211** ("1-0 series", molded). **C1 = LEFT 34-pin** (3-col, rows A…NN + 2 large power pins), **C2A = RIGHT 50-pin** (4-col). Pin-1 datum = the **"01" + AMP** end on each. *(Open only: confirm housing-vs-contact P/N + contact gender when ordering the mates — or skip it and go Path B taps.)*
- **Output relay → connector map:** S→C1 **(C,D,N,T)** · T→C1 **(A,K,H,E,+L)** · M2→C2A · SP→C2A · M→C2A **(FF,U,B)** · BE→C1 (KK,C,L + coil FF@66Ω) + C2A. (S = C not J; T = L not P — both corrected.)
- **Coil voltages:** Siemens 3TH4022 = 5Ω = **24 VAC** · M/M2 (82-70-5515) = 80Ω · SP = 100Ω · BE = 22Ω (all ~24 V native) · P&B JRM-10110 = **12 VDC**.
- **Cam-stop topology:** the Omega-Tek board is a triac + CMOS driver bank → **LOGIC stops** (cams route *through the board*, not hardwired in series with the coils). This **confirms the plan** — the Pi/RP2040 times the stops and we add hardware end-stops. (A final at-machine cam-flip proof is a nice-to-have, not a build gate.)

---

## 🔵 What's REMAINING (the real list)

### ✅ Confirmed at the machine (2026-06-27)
- **Grippers (drop-a-pin) — COMPLETE 10/10:** GS1=**C** · GS2=**H** · GS3=**M** · GS4=**S** · GS5=**W** · GS6=**a** · GS7=**e** · GS8=**K** *(✓ 2026-07-07)* · GS9=**r** · GS10=**v**. (GS1–5 match the schematic; GS6–10 resolve/correct it — the old GS8=48H collided with GS2=H, and GS10=U is a common, both wrong. GS8=K breaks the loose alphabetic run — measurement over pattern; the cutover drop-one-pin gate re-verifies each anyway.)
- **PBZ** (zero button) **→ EE** (shorts to common U when pressed).
- **BS** (#9 bin) **→ CC.**
- **SC** cold trace **→ U.** · **TB → no standalone cavity** (neither TB lead isolates from the shared U live-ladder region; this is a harness fact, not a topology result).
- **Common/ground rails — ignore these, they ring to everything:** **J, F, U** (gripper/control common, chassis return) + **N** (the 5-cam motion common).
- **Deferred to powered cutover:** motion cams **SA / SB / TA1 / TA2** (buried in the relay ladder — a clean one-read each once powered).
- **Still open:** GP (gripper-protect — **DEFERRED 2026-07-07 to a later session or the powered cutover**; predicted ~412DD, no manual photo exists, method = watch DD/sweep while working one gripper's fingers fully open) · OS / PBC / 10th / MAN_* (spare/future) · Foul · DIELL re-check.

### ★ 1. C2A INPUT cavity digits — largely CLOSED 2026-06-27 (see ✅ block above)
**Remaining cold work = GP + the ⊕ stragglers.** The four motion cams (SA/SB/TA1/TA2) map at **POWERED cutover only** (§3) — do **not** re-attempt them cold. The reach-lead procedure below is kept for the remaining stragglers. The cams/grippers/switches live on the **machine**; their wires reach the cabinet through C2A.

**The reach problem + the fix.** C2A is in the cabinet, the cams are out on the mechanism — too far for two meter probes. **Don't buy long probes — use a long extension lead.** Grab **~25 ft of stranded hookup wire with an alligator clip on each end** (or chain 2–3 alligator test-lead sets — about $10). Clip one end to the device's signal terminal at the machine, run the wire back to the cabinet — you've now "brought" that terminal to you, and **both meter probes work at the cabinet**: one on the long lead (= the device), the other sweeping C2A.

**Procedure (per device, cold, continuity/beep):**
1. **Anchor** the long lead's clip on the device's **signal terminal** (per-type guide below). One device at a time — label the clip so you don't lose track.
2. **Sweep at the cabinet:** one meter probe on the long lead; with the other, **back-probe** the C2A cavities (a back-probe pin slides in beside the wire from the rear — no need to un-mate). The cavity that **beeps** is the pin. *(Or un-mate C2A and probe the cabinet-side cavities directly — same cavity number either way.)*
3. **Confirm (cams):** rotate the mechanism to trip that cam — the beep should appear/drop. That's the lock.
4. **Record** the cavity as column letter + count from the **"01" + AMP** datum end.

**Where the "signal terminal" is, by device:**
- **Cams (SA/SB/SC/TA1/TA2/TB):** each is a lever microswitch (COM/NO/NC). Clip to the terminal whose **wire heads into the C2A harness bundle**, not the one to the shared common/return. Unsure → try NO; if nothing beeps, try COM.
- **Grippers (GS1–10):** the spotting-table pin-presence switches. ⚠️ **Correction from the at-machine trace (2026-06-03):** there is **no physical TAC terminal strip** — each gripper switch closes to the **machine chassis/frame** (the chassis *is* the common return), and its signal wire runs in the table harness straight to a C2A cavity. So **don't clip-and-sweep the grippers — map them by dropping a pin** (see the gripper note under the table).
- **Pushbuttons (PBZ/PBC):** the button terminal that isn't the common.

| Device | Clip the long lead to… | Beep / sweep at C2A | Priority | Reading |
|---|---|---|---|---|
| **SC** | sweep-under-table interlock cam (pink lead) | **→ C2A-U cold trace** ✓ 2026-06-27; live-ladder node, not a dry landing | ★ HIGH | **U (location only)** |
| **TB** | table-sweep interlock — neither lead isolates from the SC/U live-ladder region | **no standalone cavity** ✓ 2026-06-27 (no independent observation) | ★ HIGH | — shared region |
| **TA2** | table run-through cam switch | ~~confirm 21A, else 30N~~ cold read INVALID (30N impossible — N = cam common; coil sneak paths) | **DEFERRED → powered cutover (§3)** | — |
| SA | sweep cam (270/360) switch | ~~confirm 31N~~ cold read INVALID (N = cam common) | **DEFERRED → powered cutover (§3)** | — |
| SB | sweep guard cam switch | ~~confirm 31H~~ cold read INVALID | **DEFERRED → powered cutover (§3)** | — |
| TA1 | table cam (355/185) switch | ~~confirm 34N~~ cold read INVALID (N = cam common) | **DEFERRED → powered cutover (§3)** | — |
| GS1–GS10 | drop-a-pin (chassis return) | **✓ 10/10:** 1=C 2=H 3=M 4=S 5=W 6=a 7=e **8=K** 9=r 10=v | done | see ✅ block |
| GP / BS | gripper-protect / bin (#9) switch | **BS → CC ✓**; GP still open | confirm | BS=CC |
| PBZ | zero pushbutton terminal | **→ EE ✓** (shorts to common U pressed) | confirm | EE |
| OS / TENTH / MAN_SWSR (⊕) | off-spot / 10th / man-reverse switch | **SWEEP — unknown** | LOW | ____ |
| MAN_T / MAN_S / MAN_SWS (⊕) | manual table / sweep / sweep-switch | sweep T/S/SWS region | LOW | ____ |

> **Status (post-2026-07-07): the cold campaign is CLOSED.** SC/TB, all 10 grippers, PBZ, BS done; **GP deferred by decision** (catch it at the powered session — it gates nothing in the harness build; J4-11 lead gets cut/labeled but not landed). TA2 and the other motion cams map at the powered session (§3).

**Grippers — map by dropping a pin (cold; no reach lead needed).** Because every gripper returns to the machine frame, you don't trace each one — you *actuate* it. Machine cold: clip your meter's **black lead to bare chassis/frame**, then **set a single pin into one spotting cup** (or hand-close that one gripper). With the red lead, **back-probe the C2A cavities** — the cavity that now reads **closed to chassis** is that gripper. The pin you dropped tells you the **gripper number** (its pin position, 1–10), so this step *names* GS1…GS10 at the same time. Work one cup at a time across the triangle. (This is the cutover "drop a pin, watch which input asserts" step from §4.3 — doing it with a meter at the bench gets you the cavity map early.)

**Cam switches — probe the WIRE by color, not the switch terminal** *(now relevant to the POWERED session only — cold per-cam mapping is invalid, see below)*. The cam microswitches are subminiature (tiny plunger + lever) and their terminals are at the back, nearly unreachable. You don't need them — tap the cam's signal **wire** instead: an **insulation-piercing probe**, or a **sewing pin pushed through the insulation** with the long lead clipped to the pin. The board reads the **motion cams (SA/SB/TA1/TA2) normally-closed** → clip their **N.C.** wire; **SC and TB are the interlock cams**, read on their **N.O.** (window) contact → clip the **N.O.** wire. Colors are **per-harness** — the sweep-switch and table-switch harnesses reuse colors (SB's brown ≠ TB's brown), so use the right table for the switch you're on. From the p257 wire legend:

*Sweep switches (SA / SB / SC):*
| Cam | Clip the N.C. wire | (N.O.) | (COM — avoid) | lands on |
|---|---|---|---|---|
| SA | **WHITE** | blue | black | TS-31 |
| SB | **BROWN** | red | bused → SA | TS-16 |
| SC | **PINK** (N.O.) | yellow = N.C. | green = COM | **→ C2A-U** ✓ 2026-06-27 |

*Table switches (TA1 / TA2 / TB):*
| Cam | Clip the N.C. wire | (N.O.) | (COM — avoid) | lands on |
|---|---|---|---|---|
| TA1 | **PINK** | purple | black | TS-30 |
| TA2 | **BLUE** | gray | bused → TA1 | TS-33 |
| TB | *(N.O. only)* **GREEN** | — | brown | TSA-5 |

**SC/TB reconciliation:** the cold 2026-06-27 trace located SC at TSG-1/C2A-**U** and proved **TB has no independent cavity or dry pair**; neither TB lead isolated from that live-ladder region. Because the same cold measurements include ~21 Ω relay-coil sneak paths, they did **not** establish contact topology or danger polarity. The powered 2026-07-07 test is authoritative: the OEM contacts behave **parallel closed-when-safe**; either pressed lever permits a coil and **both levers BACK/open kill both S and T coils**. Candidate C therefore uses the controlled J_SAFE1-2 jumper and keeps the OEM ladder primary, subject to a per-lane G3 S/T coil-drop proof. Do not treat U as a dry J_SAFE or firmware-input landing; the SC∧TB firmware echo remains default-off, secondary, and unvalidated because no independent TB observation exists.

**Motion cams share a COMMON → C2A-N.** The cam COM wires bus together to one cavity, **N** (confirmed 2026-06-27 — both SA and TA2 ring to N regardless of lever). Because they share this common, **cold per-cam cavity reads are ambiguous** (every cam shows N + maybe its own cavity). **Finish the per-cam SA/SB/TA1/TA2 → cavity mapping at powered cutover** — rotate the mechanism, watch which cavity goes live as each cam trips (§4.2 PART C2); it does **not** gate the board. Cold sweeps also pick up **sneak paths through relay coils** — SA's lower wire reads ~21 Ω to CC (a coil path, ≈BE's 22 Ω coil) plus ~0 Ω to N/FF/F (commons). Those paths prove the region is not an isolated dry harness and make cold topology inference invalid; they do not prove whether the safety contacts themselves are series or parallel. **Do the mapping powered** (rotate, watch the cavity go live).

> **⛔ COLD CAM MAPPING IS A CLOSED METHOD — DO NOT ATTEMPT A THIRD TIME (2026-07-24).**
> Attempted twice at the machine (2026-06-27, and again 2026-07-24 via the "lever differential"
> trick with C2A unmated). Both failed the same way: no clean per-cam closure to N appears at
> rest, the only low-ohm hits are the documented commons (**F** rang <3 Ω to N — it is a common,
> not a cam) plus unstable higher-resistance sneak paths (lowercase **t**), and readings are not
> reproducible enough to identify anything. Meter/leads verified good during the 2026-07-24
> attempt, so this is the method failing, not the instrument.
>
> **The only approved path is POWERED, AT THE CAM SWITCH TERMINALS** (not at the connector):
> machine running under OEM control, clip onto a cam switch's own terminal, watch it through a
> cycle. That yields identification **and** the mandatory voltage class in one operation — and
> the class is the answer that actually matters before any cam lead touches a PC817 (this
> machine has produced 33 VDC on PBZ and 42 VAC on the DIELL board's middle block).
> **Fallback if connector-side identification stays impractical: tap the cams AT THE SWITCHES**
> and skip C2A for those four channels entirely — four extra wires to route, zero identification
> problem.
>
> **Not on the critical path.** Stage 6b (first commanded motion / coil-drop proof) needs the
> output taps and the rail, not cam inputs. Cam signals are required only for full FSM cycle
> timing, which is after first motion. Priority order stands: **Stop/CIS landing → output taps →
> Stage 6b → cams.**

**Isolate it (for one clean beep):** actuate the switch to the state that **opens the contact you're reading**, so that wire disconnects from the bused common — then only its own cavity beeps. **N.C. (motion cams): press** the lever to open it. **N.O. (SC/TB interlock): release / pull the lever off** the button to open it. (Or skip isolating and just take the single *unique* cavity, ignoring the common-bus beeps.)
**Even easier if it survived the retrofit:** every wire lands on a numbered terminal strip (the "TS-nn" above). If that strip is still in the machine, clip there instead of piercing.

### 2. Short stragglers (knock out alongside)
- **M1 (ball-return) output** — never measured. Only needed if you ever populate J12 (DNP). Low priority — beep its coil → connector when convenient.
- ~~**Heavy-lug S/T contactor coil V**~~ **✓ CLOSED 2026-07-07: both S and T motor-contactor coils = 24 VAC** (measured live across A1–A2 during the interlock test-2A session). The suspect T<1Ω cold read is moot for the harness (it was a contact, not the coil — the live coil reads confirm).

### 3. At-machine, POWERED (during cutover prep — one deliberate test at a time, locked out otherwise)
- **Front-end class (dry vs 24 VAC):** **no reach problem here** — meter each actually observable cam cavity at the cabinet with a loaded/LoZ probe. **< 2 V or open = dry** (keep the opto front-end); **12–24 VAC = live** (that channel needs the 24 VAC-rectified sense). SA/SB/SC/TA1/TA2 are the observable candidates; **TB has no independent cavity on lanes 21/22 and must not be invented as a sixth input.** C2A-U remains unlanded unless a separately reviewed observe-only input design is released.
- **Foul tap:** meter the foul **lamp wire** voltage → decide dry vs 24 VAC front-end for J5-3.
- **DIELL re-check:** signal line ~16 V beam-clear / ~0.7 V blocked (already proven). Tap **signal + GND only** into J3-7/8.
- **Safety chain (§A):** stop switch RUN → coil rail live; STOP → dead. **Break-on-STOP = hardware-in-series (preserve).** No break = **FLAG: add hardware interlock before any Pi-driven motor.**
- **Cam-stop actuation (§B):** flip the cam — does the motor-relay coil drop **from the cam alone** (hardwired) or **only after the board reacts** (logic)? Confirms the topology read. *(This one needs eyes on the coil while flipping the cam — easiest with a helper, or clip a 12/24 V test lamp across the coil so you can watch it from the mechanism.)*

---

## Safety (the bits still live)
- The cold C2A tracing (#1) is **continuity only — safe.**
- For the powered steps (#3): **lock out**, power only for the one deliberate test, **load the probe (LoZ)** to kill ghost voltage, **never cut the safety loop to measure** (bridge across it), and confirm the caps read ~0 V before handling.

## Tools
DMM (continuity/beep, AC + DC volts, **LoZ/low-Z** mode if it has one), **back-probe pin kit** (touch a C2A cavity without un-mating), **a ~25 ft extension lead** (stranded wire + 2 alligator clips, or 2–3 chained test-lead sets — bridges the cabinet↔machine reach for B1), clip leads, the Section F spec printout, phone camera, this sheet.

## What to send back
Photos or typed copy of the **B1 table** (+ any straggler readings). I turn them straight into the corrected Section F input map — and the harness goes from spec to cut-and-crimp.

> **Bottom line (reconciled 2026-07-24):** the cold tracing is **done** — it located the shared SC/U region, proved no standalone TB/dry pair, and measured all 10 grippers, PBZ, and BS. It did **not** prove SC/TB topology; the powered result controls and is parallel closed-when-safe. Remaining cold = **GP + ⊕ stragglers**; the four motion cams map at **POWERED cutover** (§3). The bench output side was already done.

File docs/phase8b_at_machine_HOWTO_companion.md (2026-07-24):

# At-Machine Field Sheet — Beginner's Companion (how to actually do each measurement)

> ⛔ **RETIRED 2026-06 FIELD-SESSION COMPANION — DO NOT EXECUTE ITS B1 TB/SC
> PROCEDURE OR USE IT TO WIRE J_SAFETY.** Cold continuity cannot establish topology
> in the ~21 Ω coil-ladder sneak paths, and lane 21/22 has no dry/independent TB
> pair. Powered 2026-07-07 evidence proved the OEM contacts are parallel
> closed-when-safe and both levers BACK/open kill S/T. Candidate C uses only the
> controlled J_SAFE1-2 jumper, preserves the OEM ladder, and requires per-lane G3
> coil proof. Use the current interlock redesign, lane harness build sheet, and
> Track-B runbook for any new work. The body below is historical procedure context.

**Read this alongside `phase8b_at_machine_fieldsheet.md`.** It answers: exact probe points, how to measure current, how to tell dry-contact vs voltage-sense, where each cam physically is, and step-by-step Parts B & C. Written assuming you've used a multimeter for continuity/resistance (you have) but not much else. No prior current-measurement or live-mains experience assumed.

---

## ⭐ FIRST — good news that shrinks this whole session
Your **bench data already answered most of Part A.** You measured every coil and proved they're all **24 V**: S = 24 VAC (confirmed from the Siemens part number), M/M2 = 80 Ω, SP = 100 Ω, BE = 22 Ω — all fed by the machine's 24 V transformers (T2/T3/T4).

So the live session is mostly **confirming 24 V**, not discovering unknown voltages. That means:
- **A1 becomes a quick confirm**, not a hunt. You're checking "yep, ~24 V" on each, not finding surprise 120 V.
- Less time with hands near a powered machine = safer.
- If every A1 read is ~24 VAC (very likely), the board's isolation spacing can relax — that's the payoff.

**If you do only one thing live: confirm S and one other relay read ~24 VAC. That alone is most of the value.**

---

## METER SETUP (one-time, before you start)
Your multimeter has a rotary dial. You'll use four settings:
- **Ω (ohms / continuity)** — the one you already know. Beeps or shows low number = connected.
- **V~ (AC volts)** — wavy line. For 24 VAC coil circuits. Set range to 200 V (or autorange).
- **V⎓ (DC volts)** — straight line + dashes. In case something's DC.
- **A (amps)** — covered in the current section below. You likely WON'T need this (see A2).

**Probe rule for everything live:** **black probe clipped to bare chassis metal** (a frame screw) and **leave it there**. You move only the **red probe**. This keeps one hand free and gives every reading a common reference. Use an alligator-clip lead on black if you have one — then you're truly one-handed.

---

## A1 — RELAY WORKING VOLTAGE: exact probe points

**The concept in one sentence:** the existing controller energizes each relay's **coil** to make the machine do a thing; we measure the voltage on that coil so we know what our board's contact will be switching.

**Black probe:** chassis ground (clip it, leave it).
**Red probe:** touch the relay's **coil terminal** — the same terminals you already found on the bench. From your bench notes:

| relay | where it is in the cabinet | coil terminals = red-probe point |
|---|---|---|
| **S** (sweep) | upper-right, the **Siemens 3TH40** | **A1** (top) and **A2** (bottom) — the screw terminals your white wires landed on |
| **T** (table) | upper-right, the contactor next to the Siemens | its two coil terminals (the mid-resistance pair you found) |
| **SP** (spot) | lower-center ice-cube relay (100 Ω coil) | its two coil terminals |
| **BE** (back-end) | lower-left (22 Ω coil) | its two coil terminals |
| **M** (master) | lower-center (80 Ω coil) | its two coil terminals |
| **M2** (sweep-rev) | lower-center (80 Ω, identical to M) | its two coil terminals |

**Procedure per relay (this is the [LIVE] part):**
1. Machine powered, **but make the relay actually energize for its function** — e.g. for S, the sweep has to be called. Easiest: have your helper run a normal machine cycle (throw/trigger a ball or use the manual cycle button) while you watch the meter. The coil is only "live" when that function is active, so you're catching it during the cycle.
2. Red probe on **one coil terminal**, black on chassis → read **V~ (AC)**. Note it.
3. If AC reads ~0, switch to **V⎓ (DC)** and read again (some could be DC).
4. **Expected: ~24 V (AC for S, likely AC for the rest).** Write it in the A1 table.
5. **Simpler alternative if catching it live mid-cycle is hard:** measure across the coil terminals (red on A1, black moved to A2 instead of chassis) — same reading, and you can do it the instant the relay clicks.

> **Safety:** you're touching **low-voltage coil terminals (~24 V)** — uncomfortable but not dangerous. **Do NOT** probe the fat motor wires or the 115 VAC input. If you're not sure which terminals are the coil vs the motor contacts, the coil terminals are the **thin wires**; the motor contacts are the **thick/heavy wires**. Stay on thin.

---

## A2 — HOW TO MEASURE CURRENT (you probably don't need to — read this first)

**You likely can skip A2.** Here's why: the board's relay (G5LE) has a **10 A contact**, and these coil circuits draw well under 1 A (a 24 V coil at 22–100 Ω pulls ~0.25–1 A; the Siemens AC coil a bit more on inrush). 10 A >> 1 A by a huge margin, so the contact is fine **without** an exact number. **Recommended: skip the live current measurement; note "coil circuits, <1 A, G5LE 10 A contact = ample" and move on.** Less risk, and the rating decision doesn't actually need the precise number.

**If you want the number anyway, here's how — and the safe way vs the risky way:**

Current is different from voltage: to measure voltage you *touch two points* (parallel). To measure current the old way you must **break the circuit and insert the meter in line (series)** — that means disconnecting a wire, which on a live machine is fiddly and easy to get wrong. **Don't do that.**

**Use a clamp meter instead (the safe, no-contact way):**
- A **clamp meter** has a hinged jaw. You open the jaw, put it **around a single wire** (just one — the coil's hot lead), close it, and it reads the current flowing through that wire **without touching anything**. No breaking the circuit, no disconnecting.
- Set it to **A~ (AC amps)**, clamp around **one** coil wire (not both — both cancels out), run the cycle, read the number during the moment the relay is energized.
- ~$30 clamp meter is the right tool; if you don't have one, **skip A2** (the G5LE 10 A margin makes it non-critical).

**Bottom line for A2:** skip it unless you happen to own a clamp meter. The relay rating is safe either way.

---

## A3 — MASK LAMP SUPPLY (same method as A1)
The status lamps (1st-ball, 2nd-ball, strike, foul) are on the **mask** (the lit panel above the pins). Their supply is brought to the mask connector.
- **[LIVE]:** black on chassis, red on a **lamp terminal at the mask connector** while that lamp is lit (run a cycle that lights it, or it may be on at rest).
- Read V~ then V⎓. **Expected ~12 VDC** (per the manual). Note voltage + which (AC/DC).
- That's it — current here you can eyeball: small indicator lamps, well under the PhotoMOS rating. Don't bother clamping.

---

## A4 — DRY-CONTACT vs VOLTAGE-SENSE: the simplest test

**What this question means in plain terms:** every input (a cam, a gripper, a switch) tells the controller "I'm active" in one of two ways:
- **Dry contact** = it's just a **switch**. When active, it connects two wires together (continuity). No voltage of its own. Like a light switch.
- **Voltage-sense** = when active, a **voltage appears** on the wire (e.g. 24 VAC shows up).

**The test — do it in this order:**

**Step 1 (LOCKED OUT, safe): is it a dry contact?**
- Meter on **Ω / continuity**.
- Put one probe on the input's wire/terminal, the other on chassis ground (or the input's common).
- **Actuate the input** (trip the cam by hand, lift the gripper, press the button).
- **If the meter goes from open (OL) to ~0 Ω (beep) when you actuate → it's a DRY CONTACT.** Done. Mark "dry."

**Step 2 (LIVE, only if Step 1 showed no continuity change): is it voltage-sense?**
- Meter on **V~ (AC)**, black on chassis, red on the input wire.
- Actuate / run the machine so the input goes active.
- **If a voltage appears (e.g. ~24 V) when active → it's VOLTAGE-SENSE.** Mark "AC, ___V."

**That's the whole test.** Most machine switches are dry contacts (Step 1 catches them). You only go live (Step 2) for the ones that *don't* show a continuity change.

---

## WHERE EACH CAM PHYSICALLY IS

**What a cam switch looks like:** a small **microswitch** (lever or roller arm, ~1 inch, 2–3 wires) mounted so a rotating **cam lobe** (a bump on a disc/shaft) pushes the lever once per revolution. You're looking for little switches with a roller riding on a shaft-mounted disc.

**The 6 cams live on two shafts:**

**SWEEP cams (SA, SB, SC)** — on the **sweep drive**, which is the mechanism that swings the sweep bar (the rake that clears dead wood). Find the **sweep motor** (front-end, drives the sweep), follow its shaft — the cams ride on that shaft / its gearbox output. There are 3 microswitches clustered there:
- **SA** = stops sweep (the 270°/zero one)
- **SB** = the guard-stop (66°)
- **SC** = the interlock cam (sweep-under-table)

**TABLE cams (TA1, TA2, TB)** — on the **table drive**, the mechanism that lowers/raises the spotting table (the part that sets pins). Find the **table motor**, follow its shaft — 3 microswitches there:
- **TA1** = table zero/355°
- **TA2** = run-through/260° (the pin-read trigger)
- **TB** = the interlock cam (table-sweep interference)

**How to confirm which is which (you don't have to ID them perfectly at the machine):** for the harness map (Part C) you'll trip each one and watch which C2A cavity reacts — that *tells* you which is which, so you don't need to read tiny labels in the machine. Just find "the cluster of ~3 microswitches near the sweep motor" and "the cluster of ~3 near the table motor."

> **Reference:** the AMF "Front End" parts manual (`Downloads/Pinspotters 82-70_Front End.pdf`) has the sweep + table drive exploded views (pages 2, 8) if you want to see the assemblies. But honestly, finding "3 microswitches on the sweep shaft / 3 on the table shaft" by eye is faster than the diagram.

---

## PART B — SAFETY-ARCHITECTURE CHECKS (step by step)

These confirm the machine's existing safety wiring so our board plugs in without defeating it. **All can be done LOCKED OUT (safe).**

### B1 — TB/SC interlock: how it's wired
**Plain meaning:** TB and SC are the two "collision" cams. If the table and sweep are ever about to hit each other, this interlock cuts power to both motors. We need to see how it's wired so our board's safety connector matches it.
**Steps (LOCKED OUT):**
1. You already located TB (table shaft) and SC (sweep shaft) above.
2. Meter on **continuity**. Probe across the TB switch terminals; hand-rotate so TB trips. Confirm it **opens** (goes from beep to open) when tripped — that's a "normally-closed, opens-on-danger" switch. Note: TB opens when tripped? Y/N.
3. Same for SC. Note: SC opens when tripped? Y/N.
4. Trace where their wires go: do TB and SC connect **together** (in parallel) and then into the 24 V control line? Follow the two wires; if they join, that's the parallel interlock. Photograph the junction.
5. **What to send me:** "TB opens Y/N, SC opens Y/N, they join at ___ , photo attached." That's enough for me to wire our J_SAFETY connector correctly.

### B2 — Are the motor stops hardwired or done by the board?
**Plain meaning:** when a cam says "stop," does it cut the motor *directly* (hardwired), or does it just tell the controller, which then stops the motor (logic)? Affects whether we keep a bonus hardware backstop.
**Steps (LOCKED OUT):**
1. Meter on continuity across the **S relay coil terminals** (from A1).
2. Hand-rotate the sweep so the **SA cam** trips.
3. Watch the meter: does the **coil circuit open the instant SA trips** (→ hardwired), or does nothing change at the coil (→ the board does it = logic)?
4. Note: "SA trip opens S-coil directly? Y/N." Repeat with a table cam + T-coil if easy.
5. (Expected: logic — nothing changes at the coil. Either answer is fine; it's informational.)

### B3 — Stop button / safety chain
**Plain meaning:** confirm the big Stop switch actually kills motor power in series (it should).
**Steps (LOCKED OUT):**
1. Find the machine's **Stop switch** (and the C.I.S. safety switch if present).
2. Meter continuity from the **motor-relay coil supply** to the **power-in**, through the stop switch.
3. Flip Stop to STOP → continuity should **break**. Flip to RUN → continuity returns.
4. Note: "Stop breaks the coil supply? Y/N." (Should be Y.)

---

## PART C — HARNESS MAP (which machine wire = which board signal)

**Plain meaning:** our board has function-named inputs (GS1, SA, etc.) but the actual machine wires land on the C2A connector in some order we haven't mapped. This is where we map "machine signal → C2A cavity." Now that the machine's here, we can **actuate each input and watch which cavity reacts** — impossible on the dead bench, easy now.

**The universal method for all of Part C (LOCKED OUT):**
1. Meter on **continuity**, black on the input's **common/return** (or chassis).
2. Red probe on a **C2A cavity**.
3. **Actuate the one input you're testing** (lift a gripper / trip a cam by hand / press a button).
4. Sweep the red probe across C2A cavities until you find the one that **changes** (open↔closed) exactly when you actuate. **That cavity = that signal.** Record it.

### C1 — the 10 grippers (GS1–GS10)
The grippers are the little fingers on the spotting table that grab pins. Lift/squeeze **one** by hand → find the C2A cavity that closes → that's that GS number. Repeat for all 10. (Tedious but mechanical. Record GS1→cavity, … GS10→cavity.)

### C2 — the 6 cams
Hand-rotate the sweep/table so **one** cam trips → find the C2A cavity that changes → that's that cam. You'll also learn which cam is which this way (the one that trips at the sweep-stop position is SA, etc.). Record each.

### C3 — GP / OS / BS / Foul / PBZ / PBC
Actuate each (GP/OS/BS are machine switches you trip by hand; PBZ/PBC are operator buttons you press; Foul you can simulate at the foul unit) → find its C2A cavity. Record each.

> **Part C is the most time-consuming and the LEAST safety-sensitive** (all locked-out continuity). If you run low on time/energy, do the grippers (C1) first — they're the scoring-critical 10 — and let cams/switches trickle.

---

## YOUR REALISTIC PLAN (priority + safety)
1. **A1 confirm (LIVE, ~15 min):** S + one or two others read ~24 VAC. ← the payoff measurement. Helper runs cycles; you watch the meter; black clipped to chassis.
2. **A3 (LIVE, 5 min):** mask lamp voltage.
3. **A4 (mostly LOCKED OUT):** dry-vs-AC on the cams/switches — Step 1 continuity catches most.
4. **B1/B2/B3 (LOCKED OUT):** the three safety traces.
5. **C1 grippers (LOCKED OUT):** the 10-gripper map. C2/C3 if time.
6. **Skip A2** unless you own a clamp meter.

**Send me:** filled tables (photos of your jottings are fine) + photos of the TB/SC junction, the mask lamp point, and any contactor nameplate. I'll turn A1 into the final board spacing, A3 into the lamp part, B into the safety wiring, C into the harness pinout.

**You've got this.** It's a lot of small, individually-simple steps — none of it is harder than the bench resistance work you already did well. The only genuinely "live" parts are A1 and A3, and those are low-voltage coil/lamp terminals with one hand in your pocket.

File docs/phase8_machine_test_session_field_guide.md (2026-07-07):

# Machine Test Session — Field Guide (post-review remaining reads)

Covers everything left that needs the machine: **Part 1** cold quick wins (GS8, GP) · **Part 2** the POWERED interlock characterization (redesign doc §4 — this is what unblocks your A/B/C decision) · **Part 3** optional same-session powered cam mapping + front-end class. Written 2026-07-07; reads-with `phase8_interlock_redesign.md` §4 and the metering guide's measured record.

**The safety trick that makes Part 2/3 easy: UNPLUG THE MOTORS.** The machine has per-motor **disconnect plugs** (labeled on the svc p29 / p15 diagrams, near the Russell-Stoll main plug at the back). With the S (sweep) and T (table) motor plugs separated, the **control circuits stay live** — contactors still pull in and click — but **nothing on the machine can move.** Every powered answer we need lives in the *coil/control* domain, not the motor domain, so you can take every reading with the mechanism dead. Verify before starting: press manual Sweep for a half-second — you should hear the contactor **click** but see **no motion**.

## Tools
DMM with **LoZ** mode (kills ghost AC readings — use LoZ for every powered voltage read) · back-probe pins · the ~25 ft clip lead · 2 small **spring clamps or clothespins** (to hold cam levers — never fingers) · phone camera · this sheet + a pen.

## Safety rules (Part 2/3)
1. **Motors unplugged** (S + T disconnect plugs) before any powered test. Re-verify after any plug re-seat.
2. One deliberate test at a time; power OFF between test setups.
3. **Never cut or lift the safety-loop wiring to measure — bridge/probe across it.**
4. Levers get clamped, not held; body clear of the mechanism whenever power is on (even unplugged — habits).
5. Caps CP2/CP3 ~0 V before reaching into the cabinet.

---

## PART 1 — Cold (machine OFF). ~15 minutes.

### 1A. GS8 re-drop (the missing gripper)
1. Black lead clipped to bare **chassis/frame**.
2. Set one pin into **cup 8** (back row, second from left when facing the machine from the pit: 7-**8**-9-10).
3. Red lead: back-probe C2A cavities. The one that reads **closed to chassis** = GS8.
4. Sanity: it must NOT be C, H, M, S, W, a, e, r, v (taken) or J/F/U/N (commons). Expect a fresh letter.

**Record: GS8 = C2A-____**

### 1B. GP (gripper-protect) toggle-delta
GP closes when the grippers are **fully open** (it's what tells the brain the table is safe to descend). It's on the table/gripper mechanism — no OEM photo exists; find the one microswitch that moves when you work the gripper linkage.
1. Clip the long lead to one GP switch wire. Sweep C2A, note what beeps.
2. **Actuate the gripper mechanism by hand** (work the respot/release linkage so the grippers open and close) and watch: the cavity whose beep **appears/disappears with the linkage** is GP. Everything that doesn't move with it is common/sneak-path — ignore.
3. Nothing toggling? Move to the switch's other wire and repeat.

**Record: GP = C2A-____ (and which linkage state = closed: ____)**

---

## PART 2 — POWERED interlock characterization (redesign §4). ~45 min, the decision-maker.

**Setup for all of Part 2:** S + T motor disconnect plugs **separated** · machine powered · a helper is nice but clamps make it a one-person job.

**"Forcing the danger state"** = both interlock cam switches closed at once, exactly what happens when sweep and table are on a collision course: **clamp the SC lever pressed AND the TB lever pressed** (their N.O. contacts close in-window — you proved SC's N.O. is the pink wire on 06-27). Two spring clamps; hands away.

### 2A. THE BIG ONE — does the ladder alone kill the motors? (Candidate-C premise, §4.2)
The MP manual claims the rear-panel **manual Sweep/Table controls bypass all brain logic *except* this interlock** — which makes them the perfect probe: if the interlock still stops a *manual* command, the protection lives in the **ladder**, not the Omega-Tek brain.

**What "manual Sweep" is:** a switch on the **REAR CONTROL PANEL** — the small operator box at the back of the machine, the same box carrying the PBZ zero button you mapped to EE. Op-manual p11 legend: **S** = manual sweep, **T** = manual table (plus SWS/SWSR run/reverse). It is **NOT any cam switch** — SA/SB/SC on the shaft are sensors, they command nothing.

**Finding the right coil + the exact probe points:**
1. Motors unplugged, machine powered. Flip manual **S** ON for a second, OFF. **Something in the cabinet CLACKS** — that device is the S chain; no label-hunting needed. If TWO devices click (small relay driving a big one), use the **bigger one — the one with THICK motor wires on its terminals** (the motor contactor: the thing the interlock must kill).
2. On that device: the **two SMALL screw terminals with THIN control wires** are the coil — Siemens marks them **A1 / A2** (top + bottom corner, or both on front). This is the **same 5 Ω pair from the 06-01 bench read**. The FAT lugs with thick wires are motor contacts — stay off them.
3. **Power OFF → alligator-clip one meter lead to A1, one to A2** (clips, hands-free — never held probes on a live cabinet). Meter to **VAC, LoZ**. Power ON, read from a step back.
4. "Dead" vs "energized" is read **ACROSS A1–A2** (a differential read — chassis/ground is NOT involved): energized ≈ **24 VAC + a loud clack**; dead ≈ **0 V + silence**. Don't read coil-to-chassis — ladder nodes can float at odd voltages and fake an "energized." **The clack alone is a valid answer**; the meter just gives you a number to write down.

**The test:**
1. **Baseline:** manual **S** ON — clack, ~24 VAC across A1–A2, no motion (motor unplugged). Record the coil V (this also closes the old "heavy-lug contactor coil V" straggler). Switch OFF.
2. **Force the danger state** (clamp SC + TB levers pressed). Manual **S** ON again:
   - **No clack / ~0 V across A1–A2 → LADDER PROTECTION IS REAL** — strong evidence for candidate C.
   - **Clacks anyway / ~24 VAC → premise FALSE** — the interlock is brain-mediated on this retrofit; **candidate C is dead → candidate A** (aux switches).
3. **Drop-test variant:** manual S ON first (contactor in), *then* clamp both levers → coil should **drop to 0 V** if the ladder protects.
4. Repeat 1–3 for **T** (manual Table switch; re-find its contactor by the clack, move the clips to ITS A1/A2).
5. **Control:** unclamp ONE lever (either) → manual command should work normally again. If it doesn't, note which lever alone blocks it.

**Record (each of S and T): baseline V ____ · forced-command result ____ · drop-test result ____ · single-lever control ____**

> Interpreting a MIXED result (e.g. S protected, T not): record it exactly — the interlock may sit in only one coil path, which changes the harness plan. Don't force a clean answer.

### 2B. Where does the danger signal appear? (§4.1 — feeds candidate B′ + the software echo)
With the mechanism at rest, then with the danger state clamped (power ON, motors unplugged, machine idle — no cycle commanded):
1. LoZ meter **C2A-U → chassis**: record V at rest ____ and clamped ____.
2. LoZ meter the **TB ladder-feed side** — the TB switch wire that did NOT ring to SC's pink on 06-27 (the "upper" wire, → TSA-5): record V at rest ____ and clamped ____.
3. Whichever point shows a **clean, repeatable voltage change** between safe and danger is the usable tap. If neither changes, the observable may only exist mid-cycle — note that and stop (that itself is an answer: no static tap → B is dead too).

### 2C. Window angles (§4.3 — feeds candidate A alignment + echo timing)
Motors still unplugged. Hand-rotate the sweep shaft, then the table shaft, slowly through a revolution while watching (or beeping, power OFF for this one if easier) the SC then TB switch:
- Note where each **closes** and **re-opens** against any degree markings on the shaft/cam; no markings → photograph the cam lobe at each transition point (4 photos: SC close, SC open, TB close, TB open).
- Expected ballpark: SC ≈ 86–243° of sweep, TB ≈ 105–255° of table. Ballpark disagreement is fine — record what the iron says.

---

## PART 3 — Optional, same setup: powered cam mapping + front-end class. ~30 min.
Only if the session is going well — this is cutover-prep work, and the setup (powered, motors unplugged) is already paid for.

### 3A. Motion-cam cavities (SA / SB / TA1 / TA2) — the cold-impossible read
1. Back-probe a candidate C2A cavity; LoZ meter cavity → chassis.
2. **Hand-rotate the sweep shaft** through a revolution: a cavity whose voltage **toggles at SA's angles** (two spots: ~270° and ~360°) = SA; at ~66°/186° = SB. Repeat on the **table shaft** for TA1 (~355°/185°) and TA2 (~260°).
3. Faster variant: clip the meter to the cam's **switch wire** (colors from the p257 legend: SA white/blue · SB brown/red · TA1 pink/purple · TA2 blue/gray) → chassis, confirm which rotation angle toggles it, THEN find the one cavity that toggles in sync.
4. **Record: SA=____ SB=____ TA1=____ TA2=____** (ignore N — that's the common).

### 3B. Front-end class (dry vs 24 VAC) — decides the opto jumpers
At each mapped input (the 4 cams + SC tap + GP + BS + PBZ/EE), machine powered + idle, **LoZ** cavity → FIELD_GND/chassis:
- **< 2 V or dead** = dry contact (default opto front-end, no change).
- **~12–24 VAC** = live channel → that channel needs the 24 VAC-rectified front-end variant.
- **Record a voltage per channel** — even "0" is data.

### 3C. PBZ specifically
LoZ **EE → chassis**, idle: ____ V. Held pressed: ____ V. (You measured EE shorts to common U when pressed — this read tells us whether EE sits at a live potential when released, which decides its front-end.)

---

## What to send back
Photos of this sheet's blanks (or typed). **2A's answer alone settles the interlock decision** — everything else refines the harness. I'll fold the results into the redesign doc §7 decision record, Section F, and the firmware echo redesign the moment you send them.

## Priority if time is short
**2A → 1A → 1B → 2B → 2C → Part 3.** 2A is twenty minutes including setup and it's the one gating your architecture decision.

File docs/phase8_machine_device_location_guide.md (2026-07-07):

# AMF 82-70 — Machine Device Location Guide

Where every cam, switch, gripper, the start-switch/DIELL, and the foul unit **physically sits on the machine** — so you can find each one to clip a meter lead. Companion to **§1 of the metering guide** (`phase8_metering_guide_harness_unknowns.md`) and **§4 Machine I/O Inventory** (`manual_src/04_machine-io.md`).

**Sources** (in `WSL Systems/`): service-parts manual `UPDATED8270-service-parts-manual.pdf` (physical labeled photos/drawings) · operation/training manual `UPDATED 8270-pinspotter-operation-training-manual.pdf` (switch legend + cam timing). **Rendered diagrams:** `Downloads/machine_diagrams/`.

---

## ★ The one master diagram — service-parts p29
`svc_p29_machine_overview_HI.png` — a labeled back-end photo of the whole machine. In **one image** it calls out: **SA / SB / SC** ("Sweep Cam & Switch"), **TA1 / TA2 / TB** ("Table Cam & Switch"), **Off Spot Switch Lever**, **Sweep Motor**, **Table Motor**, **Spot Solenoid**, **A & MC Plug**, Russell-Stoll Plug, and the Shuttle/Respot/Spot levers. **Start here** — everything else below is a close-up of one device on this photo.

---

## Device-location table

| Device | Where it physically sits | Manual fig. | Diagram file |
|---|---|---|---|
| **Sweep cams SA / SB / SC** | Stacked on the **sweep-shaft**, back end, next to the Sweep Motor and the **A&MC plug** (right side of the p29 photo) | svc p29 | `svc_p29_sweepcam_crop.png`, `svc_p29_machine_overview_HI.png` |
| **Table cams TA1 / TA2 / TB** | Stacked on the **table shaft** (left-center of the p29 photo), with the Off-Spot lever | svc p29; exploded svc p257 | `parts_p257.png`, `svc_p29_machine_overview_HI.png` |
| **Cam-switch assembly (exploded)** | Bracket + microswitch + cam weldment on each shaft — how the cam/switch/bracket stack assembles | svc p256–258 | `parts_p257.png` |
| **OS — Off-Spot switch** | On the **table torque tube**; lever closed by the **Clevis** when the table hits an off-spot pin → forces 2nd-ball logic | svc p82 | `svc_p82_offspot_switch.png` |
| **BS — #9 Bin switch** | In the **bin framework between the #8 and #9 bins**; Switch Actuator Lever trips when pin #9 lands ("10 pins ready") | svc p81 | `svc_p81_bin_switch.png` |
| **SS — Start switch** (the cycle trigger; **= DIELL** on our lanes) | OEM lever on the **kickback/cushion**, tripped by cushion movement on ball impact. On 21/22 the SS *function* is the DIELL photoeye, but this shows where the cushion switch sits | svc p112 | `svc_p112_start_switch_cushion.png` |
| **Grippers GS1–GS10** | Ten respot-cell pockets on the **triangular spotting table**, in the pin triangle (see numbering below) | svc p186; cell detail p188 | `svc_p186_hi.png` |
| **GP — Gripper-protect switch** | On the **table/gripper mechanism**; closes when grippers fully open (protects table fingers). *No standalone photo in either manual* — logic input only | legend op p11; circuit Fig.18 (tm p38) | `op_p11_switch_legend.png`, `tm_p38.png` |
| **PBZ (Zero/1st-ball) & PBC (Cycle) buttons** | Pushbuttons on the **rear / back-end control panel**. *Manuals give legend + wiring only — no clean panel-face photo* | legend op p11; wiring op p34/p40 | `op_p11_switch_legend.png`, `op_p40_rear_panel.png` |
| **FOUL (Radaray)** | **Not on the pinsetter** — a foul-line accessory. *No mechanical drawing in either manual*; needs the separate AMF Radaray doc | op p11 (foul light only) | — |

---

## Gripper numbering GS1 → GS10

Standard USBC pin triangle — **gripper switch GS-N = respot cell N = pin N**:

```
        (back of deck / pit side — wide edge of the table)
     7     8     9     10      <-  GS7  GS8  GS9  GS10   (back row)
        4     5     6          <-  GS4  GS5  GS6
           2     3             <-  GS2  GS3
              1                <-  GS1  (head pin)
        (front / approach side — apex of the table)
```

- **GS1** = head pin (front apex). **GS7–GS10** = back row, along the table's widest edge.
- Each gripper switch **closes (signals) to the machine chassis** when a standing pin is lifted by that cell — confirmed even in the OEM legend ("GS gripper switch — signals chassis when pins present").
- **Cell #7 is the one mechanically-distinct unit** (its own part numbers / yoke assembly); cells 1–6 and 8–10 are the common type. Only asymmetry in the set — note it for the pin-detect harness.

> **Software label is set at cutover, not assumed.** Don't trust a physical GS# wire number to match the software channel. Map each by **dropping one pin in one cell and watching which input asserts** (metering-guide §1 gripper note). The triangle tells you where to look; the live drop locks the binding.

---

## TAC strip — OEM vs. your 21/22 machine (reconciliation)

The OEM manuals route the 10 gripper wires to a **"TAC" terminal strip, terminals 1–10** (training-manual **Fig.18** / `tm_p38.png`). Important detail: Fig.18 labels that strip **"WIREWAY ASSY — LEFT FRONT OF MACHINE"** — i.e. out at the machine's left-front, **not** in the control cabinet.

Your project's **§4.3 at-machine trace (2026-06-03)** found **no physical TAC strip in the Omega-Tek cabinet** — the gripper wires run in the table harness **direct to C2A**, with the **machine chassis as the common return**.

These reconcile cleanly: **both agree the grippers signal to chassis.** The only open question is whether the physical left-front TAC terminal block still exists on your machine or was bypassed in the Omega-Tek retrofit.

**Practical takeaway:**
- **Look** for a 10-terminal strip in the wireway at the **left front of the machine**. If it's there, it's a tidy 1–10 clip point for all ten grippers.
- If it's absent (likely on the retrofit), the grippers land direct on C2A — use the **drop-a-pin** method, which works either way and also numbers them.

---

## Quick reference legends (rendered)
- **Switch master key** — `op_p11_switch_legend.png` (defines SS/OS/GP/GS/BS/PBZ/PBC/SWS/SWSR/T/S + motors + solenoids).
- **Cam timing** — `ops_p9.png` (SA 360°/2nd-guard · SB 66° first-guard / 186° spot · SC interlock · TA1 355° · TA2 260° · TB interlock). Matches §4.2.

## Not available in these manuals
- **Rear control-panel face photo** (PBZ/PBC buttons) — legend + wiring maps only.
- **Radaray / foul mechanical drawing** — a separate AMF Radaray/Magic-Score document.
- **Full-machine wiring schematics** (svc p287/p290) exist but are too dense at page scale — net references only; crop per-region at high DPI if you must trace one net.

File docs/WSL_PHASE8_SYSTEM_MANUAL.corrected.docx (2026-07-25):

# Westside Lanes — Phase 8 Lane Controller & Scoring System

## Technical Reference & Service Manual

Baseline manual hardware: rev-B · Current controlled firmware bundle: RP2040 v1.2.3 (Rev-D-only, not flashed; measured-cam flags OFF) · Source set reconciled: 2026-07-24

SC/TB OPERATIONAL CORRECTION (2026-07-24 — supersedes every older SC/TB/J14 statement in this manual): powered testing on 2026-07-07 proved the OEM ladder uses parallel closed-when-safe contacts; either pressed lever permits a coil and both levers BACK/open kill both S and T coils. The 2026-06-27 cold trace proved only that C2A-U is a non-isolatable live-ladder region, TB has no standalone/dry J_SAFE landing, and ~21 Ω coil sneak paths prevent topology inference. Candidate C is decided: J_SAFE1-2 receives the controlled, labeled jumper; the OEM ladder is the primary guard; every lane must pass the G3 board-commanded S-and-T coil-drop insertion proof. The firmware SC∧TB echo is default-off, secondary, and unvalidated because there is no independent TB observation.

REV-D/R5 INPUT-BIAS CORRECTION (2026-07-24 — supersedes generic 10 kΩ/GPPU statements in the Rev-B chapters): the current Rev-D/R5 board has exactly forty PC817 collector pull-ups Rpu_* (R4,R6,…,R82) at 47 kΩ (UNI-ROYAL 0805W8F4702T5E, LCSC C17713). Production firmware disables RP2040 GP6–GP13 PUE/PDE, and the Pi driver commands and reads back U1/U2 MCP23017 GPPUA=GPPUB=0x00; any internal pull enabled is STOP-SHIP because it invalidates the qualified 47 kΩ-only margin and can mask an open external pull-up. Rev-B’s 10 kΩ Rpu_* value remains historical; unrelated 10 kΩ networks, including R_TAPPU_*, are unchanged. This margin change does not waive per-channel first-article FA-9 at loaded-minimum FIELD_WET_V and ≥70 °C.

STOP / PIT-ENTRY FINDING AND J_SAFE3-4 HOLD (2026-07-24 — supersedes every claim that J_SAFE3-4 is measured, landed, or implemented): OEM documents describe parallel Stop and C.I.S. devices, but physical inspection found no C.I.S. device or wiring on pilot lanes 21/22; their installed chain is Stop-only. Whether either lane has some other automatic pit-entry interlock remains unknown. Before motion, demand-test Stop for actual rear-master/control-power removal; record the C.I.S. test as N/A — device absent, never silently waived; inspect the lane and ask the mechanic whether any other device automatically removes power on pit entry. If none exists, installation of a new interlock versus an explicit, documented owner and qualified machine-safety decision is a pre-motion design gate. The board has a valid series source position at J14 pins 3–4, but the production harness leaves both leads physically OPEN / CUT+LABEL-ONLY. The field rail therefore cannot arm. Never jumper J_SAFE3-4 at the machine or at cutover. The leading interface is an externally mounted, correctly rated, galvanically isolated energize-to-prove control-power relay whose N.O. dry contact alone lands on J14.3–4, optionally in series with a separately approved new pit-entry interlock contact. A J14-only pit switch is permission gating, not an upstream final disconnect. Acceptance and periodic proof must force control-power loss and verify the sensing-relay contact is not welded/stuck closed and TP16 drops. The sensed machine voltage and all mains remain outside Rev-D and every board harness.

MAINS-INTEGRITY BOUNDARY (2026-07-24): no mains conductor is ever routed to Rev-D, J14, or a board harness. At commissioning and periodic maintenance, a qualified electrician must verify protective-earth continuity/bonding and correct hot/neutral polarity with an appropriately listed external tester and record the result. A logic-side continuity reading is not electrical-installation certification.

GENERATED EXPORTS: WSL_PHASE8_SYSTEM_MANUAL.md, WSL_PHASE8_SYSTEM_MANUAL.docx, and WSL_PHASE8_SYSTEM_MANUAL.corrected.docx are regenerated from this ordered manual_src/00–23 source set. The section sources and the live code/netlist/harness artifacts remain authoritative; do not hand-edit an export or treat its generation date as physical first-article evidence.

Status: The Rev-D design and immutable R5 fab package have been generated, but the board is not fab-ordered and is not authorized for JLCPCB ordering or controller cutover. Physical release remains NO-GO pending the recorded sign-offs, vendor-upload inspection, first-article/FA-9 qualification, powered proof, and bench gates. This manual documents the system as designed; values still to be confirmed against real hardware are marked (VERIFY: …) inline and summarized in the Open-Items Register below.

### Purpose & audience

This is the complete, top-to-bottom reference for the system that replaces Conqueror Pro (bowling ops), the QubicaAMF VDB scoring stack, and the OEM AMF 82-70 controller brain at Westside Lanes (32 lanes / 16 pinsetter pairs). It assumes a competent engineer or electrician with zero prior context on this project, and is written so that person can operate, repair, calibrate, or extend the system without the original author present. Read §1–§2 for the whole picture; use the rest as a lookup reference.

### How to use this manual

You want… | Read
The big picture + what it replaces | §1 System Overview, §2 Architecture
How the bowling machine itself works | §3 Sequence of Operation, §4 Machine I/O
The controller board (theory of every block) | §5–§10
A specific connector pinout / channel map | §11 Connector Pinouts, §12 Channel Maps
How it manufactures (net classes, DNP, fab) | §13, §20
How the board wires to the machine | §14 Machine Interface (C1/C2A + harness)
The software/firmware | §15 Firmware, §16–§17 Pi software, §18 Camera scoring
Safety — read before any powered work | §19 Safety Architecture
Deploy, bring-up, cutover, troubleshoot | §20–§22
Full BOM, cam timing, glossary, doc index | §23 Appendices

⚠️ SAFETY. This system controls an AMF 82-70 pinsetter that moves and bites, and it switches mains-powered motor contactors. Read §19 (Safety Architecture) and the lockout/tagout procedure in §21 before any powered work on a machine. The board is never the only safety device. OEM Stop/C.I.S. history must not be mistaken for the installed pilot: lanes 21/22 have a Stop-only master-breaker chain, and the existence of any other pit-entry interlock is unresolved. The TB/SC interlock stays in hardware. J_SAFE3-4 is currently open/unlanded, so the field rail cannot arm; never defeat that hold with a machine-side jumper.

### Source & maintenance

This manual was assembled from per-section source files in docs/manual_src/ (00–23). For current Rev-D work, source-of-truth order is the Rev-D netlist generator, manifest-controlled firmware, lane harness build sheet, interlock redesign, and current cutover runbook; frozen Rev-B fabrication prose remains historical. If prose disagrees with those sources, the prose has a bug.

### Open-Items Register (reconciled 2026-07-24)

Every item below is intentionally unresolved at design/fab time and resolves at the noted stage. The inline (VERIFY: …) flags throughout the manual point back to these.

# | Open item | Resolves at | See

1 | Independently landed motion-cam SA/SB/TA1/TA2 cavity/class + trip-edge polarity. SC/U stays unlanded; TB has no lane-21/22 lead. | Powered capture before new enforcement release | §14; cutover runbook §3.2
2 | Per-gripper GS# → C2A cavity (1:1 order) | Cutover (drop one pin, watch which input asserts) | §14; runbook §3.1
3 | For lanes 21/22, prove the installed Stop removes OEM master/control power; record C.I.S. as N/A — device absent; inspect/ask the mechanic about any other pit-entry interlock and, if none exists, close the new-interlock-versus-explicit-safety-decision gate. Engineer and validate the separate J_SAFE3-4 energize-to-prove control-power interface (currently OPEN/unlanded); exact C1/C2A output insertion also remains open. TB/SC is Candidate C (controlled 1-2 jumper + per-lane S/T G3 proof), not a terminal search. | Pre-motion design review and powered characterization before cutover | §14, §19, §21; runbook §3.3–3.5
4 | M1 (ball-return) existence on this chassis — stays DNP until proven | Cutover | §9, §14
5 | controller_daemon.DEFAULT_BOARDS: real I²C bus ids, UART ports, ARM + watchdog GPIOs, MCP INT lines (currently # CONFIRM placeholders) — boot overlays, pin table + the Track-A coexistence constraint in docs/phase8_pi_provisioning.md | Bench bring-up | §12, §17
6 | Capture each independently landed motion-cam polarity; enable only confirmed cam-stop paths in a new controlled release; pass first-article/bench G3 sub-tests. Stock v1.2.3 flags are OFF. | Before controller cutover | §15, §19, §21
7 | Relay contact current rating + snubber/MOV population (field-sheet A2) | At-machine coil-current measurement | §9, §13
8 | Status-LED current-limit resistor (Rled_* = 330R placeholder) | Final LED brightness selection | §9, §12
9 | SP spot-solenoid working voltage (presumed ~24 VAC; coil was inaccessible at the field session) | Cutover glance | §3, §5
10 | 24 VAC creepage relax (board is routed to conservative 250 VAC spacing; optional shrink before the 16-lane fleet run) | Pre-fleet, optional | §5, §13
11 | Hand-solder part sourcing: TRACO TMA-0505S, the Phoenix mating plugs, the Pico module (none are JLC-placed) | Procurement | §20, §23
12 | Track-A scoring soak tuning: WSL_LANE_CAMERA_SETTLE_S, pins 2 & 3 (homography-predicted), MIRROR confirm with a deliberate 7- or 10-pin | Scoring go-live soak | §18

A historical doc lists the machine mask-lamp supply as 12 VDC; the field measurement is 15 VDC. This is moot — the board drives its own status LEDs and the machine lamp supply is abandoned (§9).

### Table of Contents

1. System Overview & Purpose
2. System Architecture & Signal Chain
3. The AMF 82-70 Machine: Assemblies, Sequence of Operation & Cam Timing
4. Machine I/O Inventory (Cams, Grippers, DIELL, Foul, Mask, Buttons)
5. Rev-B Controller Board: Overview, Domains & Isolation
6. Rev-B Power Architecture
7. Rev-B Logic: RP2040 Co-processor + MCP23017 Expanders + I²C
8. Rev-B Field Inputs: PC817 Opto-isolators
9. Rev-B Machine Outputs: G5LE Relays
10. Rev-B Safety Hardware: NE555 Watchdog + Relay-Enable Rail
11. Rev-B Connector Pinouts (J1–J14)
12. Rev-B Channel Maps: RP2040 GPIO + MCP23017 Bit Maps
13. Rev-B Layout & Manufacturing Contract (Net Classes, Creepage, DNP, Test Points)
14. Machine Interface: C1/C2A Connectors & the Adapter Harness
15. RP2040 Firmware (Safety Co-processor)
16. Pi Software: The Cycle-Control FSM
17. Pi Software: IO Layer, RP2040 Link & Controller Daemon
18. Camera Pin Scoring (Track A)
19. Safety Architecture (Consolidated)
20. Operations: Network, Deployment, Build & Fab
21. Bring-up, Bench Validation & Cutover
22. Troubleshooting, Maintenance & Spares
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

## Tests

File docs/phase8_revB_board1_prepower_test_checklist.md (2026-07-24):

---
title: "WSL Phase 8 — rev-B Controller Board — Pre-Power Test Checklist"
---

# WSL Phase 8 — rev-B Controller Board
## Pre-Power Bench Test Checklist (shorts · continuity · first power)

> ⛔ **RETIRED REV-B CHECKLIST — NOT CURRENT REV-D WIRING OR CUTOVER
> AUTHORITY.** Retain only as a historical board-inspection record. Do not combine
> it with the retired Rev-B solder guide's TB/SC J14 or firmware instructions.
> Current lane-21/22 work uses the controlled Candidate-C J_SAFE1-2 jumper, the OEM
> S/T coil ladder, per-lane G3 proof, current `docs/manual_src/`, the harness build
> sheet, Track-B runbook, and manifest-verified firmware release process.

| Field | Value |
|---|---|
| Board ID / serial | ____________________ |
| Date | ____________________ |
| Tester | ____________________ |
| DMM model | ____________________ |
| Bench supply | ________ V set, ________ mA current limit |

**Derived from the live board netlist** (`wsl-phase8b.routed-manual.kicad_pcb`). Every probe point below is a real net/pad on this board. Do the phases **in order**. Do **not** apply power until Phase 0–2 pass.

### How to use the meter
- **Short checks (Phase 1):** continuity/beep + low-Ω range. "NOT shorted" = no steady beep, reads high. Caps charge through the meter, so rail-to-rail readings *climb* as C11/decoupling fill — that's normal; a real short sits steady near 0 Ω.
- **Continuity (Phase 2):** continuity/beep. "Beep" = ~0 Ω = good joint / same net. Probe the **pin metal** (top contact or back-side tail), not the plastic.
- **Diode mode** where noted (D17).
- **Reference grounds:** logic measurements → **TP2 (`GND`)**. Field-domain measurements → **TP5 (`FIELD_GND`)**. **Never bridge a meter lead across TP2 and TP5** — that defeats the U37 isolation barrier.

### Test-point locations (silk labels TP1–TP16)
| TP | Net | TP | Net |
|---|---|---|---|
| TP1 | `VCC_5V` (logic +5 V, post-D17) | TP9 | `WDOG_TIMING_NODE` |
| TP2 | `GND` (logic ground) | TP10 | `NE555_TRIG` |
| TP3 | `VCC_3V3` (Pico regulator) | TP11 | `NE555_OUT` |
| TP4 | `FIELD_WET_V` (isolated +5 V) | TP12 | `WDOG_OK_PULLDOWN` |
| TP5 | `FIELD_GND` (isolated ground) | TP13 | `ARM_PERMIT` |
| TP6 | `I2C_SDA` | TP14 | `RP2040_OK` |
| TP7 | `I2C_SCL` | TP15 | `SAFE_STOP_RETURN` |
| TP8 | `WDOG_KICK` | TP16 | `RELAY_ENABLE_RAIL` |

> **STOP CONDITIONS (any phase):** rail-to-ground short · ANY `FIELD_GND`↔`GND` continuity · current pegging the limit at power-up · any part heating. Power off and find the cause before continuing.

---

## PHASE 0 — Visual inspection (no meter, both sides, magnification)

**Bridges / defects**
- ☐ No solder balls, whiskers, or flux bridges anywhere — **top side**
- ☐ No solder balls, whiskers, or flux bridges anywhere — **bottom side**
- ☐ **A1 Pico** castellations — no bridges between adjacent castellations
- ☐ **3× MCP23017** SOIC leads (U1/U2/U3) — no lead-to-lead bridges
- ☐ **32-opto bank** (PC817 U4–U35) — no pin bridges
- ☐ **Relay pins** K1–K6 — no bridges
- ☐ **U37 (TMA-0505S)** 4 pins — no bridges

**Cold / insufficient joints** (dull, balled, not wicked through)
- ☐ All connector joints inspected — full, shiny fillets
- ☐ **J13 reseated pins** specifically — confirmed full fillets both sides

**Polarized / orientation — HAND-SOLDERED (where errors happen)**
- ☐ **A1 Pico** — pin-1 / USB edge matches silk
- ☐ **U37 (TMA-0505S)** — square pad = pin 1 = +Vin (verified pinout); body flush

**Polarized / orientation — JLC-PLACED (glance for tombstone/rotation/wrong part)**
- ☐ **D17 (SS14)** reverse-protection Schottky — cathode band toward the rail (silk)
- ☐ **D15, D16 (1N4148)** watchdog diodes — cathode bands match silk
- ☐ **D1, D3, D5, D7, D9, D11, D13 (1N4148)** relay flyback diodes — cathode bands match silk
- ☐ **C11 electrolytic** ("100 16V") — minus stripe matches silk polarity
- ☐ **K1–K6** relays all seated flat; **K7 (M1) is EMPTY** (DNP — correct)
- ☐ **D2/D4/D6/D8/D10/D12/D14 (MOV)** footprints are **EMPTY** (DNP — correct)

**Mechanical**
- ☐ Every connector body flush and square — no lifted/tilted headers

---

## PHASE 1 — Unpowered short check  ·  SUPPLY DISCONNECTED

Meter on continuity/low-Ω. These are the checks that prevent a power-on disaster.

- ☐ **TP1 (`VCC_5V`)** ↔ **TP2 (`GND`)** — **NOT shorted** (high Ω). Steady ~0 Ω → **STOP** (5 V↔gnd bridge)
- ☐ **TP3 (`VCC_3V3`)** ↔ **TP2 (`GND`)** — **NOT shorted**. Steady ~0 Ω → STOP
- ☐ **TP1 (`VCC_5V`)** ↔ **TP3 (`VCC_3V3`)** — **NOT shorted** (3V3 is regulated from 5 V, not tied)
- ☐ **J2 pin 1 (`VCC_5V_RAW`)** ↔ **TP2 (`GND`)** — **NOT shorted** (input side, before D17)
- ☐ **TP4 (`FIELD_WET_V`)** ↔ **TP5 (`FIELD_GND`)** — **NOT shorted** (U37 isolated output)
- ☐ **TP5 (`FIELD_GND`)** ↔ **TP2 (`GND`)** — **OPEN / no continuity** ← **isolation barrier**. ANY beep → **STOP**
- ☐ **TP4 (`FIELD_WET_V`)** ↔ **TP2 (`GND`)** — **OPEN** (field/logic isolation). ANY beep → STOP
- ☐ **TP4 (`FIELD_WET_V`)** ↔ **TP1 (`VCC_5V`)** — **OPEN** (field/logic isolation). ANY beep → STOP

---

## PHASE 2 — Continuity / joint integrity  ·  still unpowered

### 2A — Logic ground common (probe **TP2 `GND`** ↔ each; all should beep)
- ☐ TP2 ↔ **J2 pin 2** (`GND`)
- ☐ TP2 ↔ **J2 pin 3** (`GND`)
- ☐ TP2 ↔ **J1 pin 2** (`GND`)
- ☐ TP2 ↔ **J1 pin 12** (`GND`)
- ☐ TP2 ↔ **J13 pin 2** (`GND`)
- ☐ TP2 ↔ **C11 minus (−) terminal**

### 2B — Logic +5 V (probe **TP1 `VCC_5V`** ↔ each; all should beep)
- ☐ TP1 ↔ **J1 pin 1** (`VCC_5V`)
- ☐ TP1 ↔ **J13 pin 1** (`VCC_5V`)
- ☐ TP1 ↔ **J14 pin 1** (`VCC_5V`)

### 2C — Input rail + reverse-protection diode D17
- ☐ **J2 pin 1 (`VCC_5V_RAW`)** ↔ **D17 anode pad** — beep (same raw-input net)
- ☐ **D17 in diode mode:** J2 pin 1 (anode) → TP1 (cathode) reads **~0.3 V forward, OPEN reversed** — confirms D17 present and **correctly oriented**
- ☐ Note: J2 pin 1 ↔ TP1 is **not** a plain beep — it passes through D17 (expected)

### 2D — Logic 3.3 V and named control signals (probe TP ↔ J1 pin; should beep)
- ☐ **TP3 (`VCC_3V3`)** ↔ **J1 pin 11**
- ☐ **TP6 (`I2C_SDA`)** ↔ **J1 pin 3**
- ☐ **TP7 (`I2C_SCL`)** ↔ **J1 pin 4**
- ☐ **TP8 (`WDOG_KICK`)** ↔ **J1 pin 7**
- ☐ **TP13 (`ARM_PERMIT`)** ↔ **J1 pin 8**
- ☐ **TP14 (`RP2040_OK`)** ↔ **J1 pin 13**
- ☐ **J1 pin 5** (`PI_UART_TX`) — joint solid (no dedicated TP; ring to Pico TX pad or verify visually + wiggle)
- ☐ **J1 pin 6** (`PI_UART_RX`) — joint solid (ring to Pico RX pad or verify visually + wiggle)
- ☐ **J1 pin 9** (`MCP_INT_A`) — joint solid (ring to MCP INTA pad or verify visually + wiggle)
- ☐ **J1 pin 10** (`MCP_INT_B`) — joint solid (ring to MCP INTB pad or verify visually + wiggle)

### 2E — Field ground common (probe **TP5 `FIELD_GND`** ↔ each; FIELD domain — all beep)
- ☐ TP5 ↔ **J3 pin 9** (`FIELD_GND`)
- ☐ TP5 ↔ **J3 pin 10** (`FIELD_GND`)
- ☐ TP5 ↔ **J4 pin 14** (`FIELD_GND`)
- ☐ TP5 ↔ **J5 pin 12** (`FIELD_GND`)
- ☐ Confirm all four also read **OPEN to TP2** (already covered in Phase 1 — re-verify any that didn't)

### 2F — J13 lamp-return pins → their 330 Ω resistors (the row of "331" 0805s by J13)
- ☐ **J13 pin 3** (`LED_L_FIRST_RETURN`) ↔ **R90** — beep one pad / ~330 Ω other pad
- ☐ **J13 pin 4** (`LED_L_SECOND_RETURN`) ↔ **R93** — beep / ~330 Ω
- ☐ **J13 pin 5** (`LED_L_STRIKE_RETURN`) ↔ **R96** — beep / ~330 Ω
- ☐ **J13 pin 6** (`LED_L_FOUL_RETURN`) ↔ **R99** — beep / ~330 Ω
- ☐ **Wiggle test** on the two reseated J13 pins while probing — reading must stay solid

### 2G — J14 safety loop
- ☐ **J14 pin 1** (`VCC_5V`) ↔ **TP1** — beep
- ☐ **J14 pin 2** ↔ **J14 pin 3** — **beep** (bridged on-board, `SAFE_TBSC_RETURN`)
- ☐ **J14 pin 4** (`SAFE_STOP_RETURN`) ↔ **TP15** — beep
- ☐ **J14 pin 1 ↔ pin 2** — **OPEN** (loop open until an external NC contact closes it)
- ☐ **J14 pin 3 ↔ pin 4** — **OPEN** (second external loop)

### 2H — Motion-output terminals (relay dry contacts; J12/M1 is DNP — skip)
- ☐ **J6** (K1, S): both terminals solid joint to relay K1; no bridge to J7
- ☐ **J7** (K2, T): both terminals solid joint to K2; no bridge to neighbors
- ☐ **J8** (K3, SP): both terminals solid joint to K3; no bridge to neighbors
- ☐ **J9** (K4, BE): both terminals solid joint to K4; no bridge to neighbors
- ☐ **J10** (K5, M): both terminals solid joint to K5; no bridge to neighbors
- ☐ **J11** (K6, M2): both terminals solid joint to K6; no bridge to J10
- ☐ Note: pin 1↔pin 2 of each = relay contact (open or closed depending on G5LE NO/NC at rest) — **not** a fault by itself

### 2I — Adjacent-pin short scan (drag probes across neighbors; OPEN except noted ties)
- ☐ **J1** (20-pin) — all adjacent pairs OPEN (no two used pins share a net)
- ☐ **J2** — pin 2↔pin 3 **beep** (both GND, OK); pin 1↔pin 2 OPEN
- ☐ **J3** (10-pin) — all adjacent OPEN **except** pin 9↔pin 10 beep (both FIELD_GND, OK)
- ☐ **J4** (14-pin) — all adjacent pairs OPEN
- ☐ **J5** (12-pin) — all adjacent pairs OPEN
- ☐ **J13** (6-pin) — all adjacent pairs OPEN
- ☐ **J14** (4-pin) — pin 2↔pin 3 beep (OK); all other adjacent pairs OPEN

---

## PHASE 3 — First power-up (current-limited)

- ☐ Bench supply set: **5.0 V** (or ~5.3 V for full rail margin), **current limit ~200 mA**
- ☐ Connect supply to **J2** — **pin 1 = +5 V, pins 2/3 = GND**. Double-check polarity before switching on
- ☐ Switch on. **Steady current < ~100 mA** (Pico + 3× MCP + NE555 + pull-ups). Pegging the limit → **STOP**. → Record actual: __________ mA
- ☐ **TP1 (`VCC_5V`)** ≈ **4.6 V** (= 5 V − SS14 drop; expected). → Record: __________ V
- ☐ **TP3 (`VCC_3V3`)** ≈ **3.3 V** (confirms Pico is alive and regulating). → Record: __________ V
- ☐ **TP4 → TP5** (`FIELD_WET_V`) ≈ **+5 V isolated** (measure to TP5, not TP2). → Record: __________ V
- ☐ **TP5 ↔ TP2 still OPEN under power** (isolation holds live)
- ☐ **No part hot** — finger-touch A1, U37, U1/U2/U3 (MCP), the NE555, the FETs, K1–K6. Anything more than mildly warm → **STOP, power off**
- ☐ **TP16 (`RELAY_ENABLE_RAIL`)** — record state (likely held LOW until firmware drives the watchdog kick + ARM): __________ V

---

## RESULT

- ☐ **PASS** — all phases clean; board cleared for functional bring-up (I²C enumerate MCPs @ 0x20/0x21/0x22, relay-click, watchdog rail-drop)
- ☐ **HOLD** — issue(s) found (note below)

**Notes / anomalies:**

________________________________________________________________

________________________________________________________________

________________________________________________________________

| | |
|---|---|
| Tester signature | ____________________ |
| Date / time | ____________________ |

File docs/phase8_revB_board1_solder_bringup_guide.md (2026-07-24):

# WSL Phase 8 rev-B — Board #1 Hand-Solder & First-Power Guide

> ⛔ **RETIRED REV-B GUIDE — DO NOT USE FOR CURRENT J14 WIRING, FIRMWARE
> FLASHING, OR CUTOVER.** The body intentionally preserves the original Rev-B bench
> procedure and therefore repeatedly labels J14 pins 1–2 as a TB/SC loop and
> references v1.1 artifacts. For current Rev-D work, J_SAFE1-2 is only the
> controlled Candidate-C jumper; OEM TB/SC protection stays in the S/T coil ladder
> and requires per-lane G3 proof. Use the current `docs/manual_src/`, interlock
> redesign, lane harness build sheet, Track-B runbook, and the manifest-verified
> firmware release process. Do not flash the paths or binaries named in this
> retired guide.

**Scope:** the hand-solder pass on a JLC-assembled rev-B lane-controller board, then the **logic-only bench bring-up** (spec §12.9). The board is **not on a machine** — the only hazards here are ESD and solder shorts to the board, not machine motion. This is the gate that proves one assembled board before any machine work.

**How this was built:** six sections, each grounded agent-by-agent in the live design files — pinouts from `scripts/generate_kicad_netlist_revB.py`, test points + thermal-mass from `13_layout-mfg.md`, the rail-fit order from `06_board-power.md`, the bring-up sequence from `21_bringup-cutover.md`, and the flash steps from `firmware/rp2040/README.md`. Where a fact isn't fixed in the sources it's flagged `(VERIFY: …)`.

---

## What's on the board vs. what you solder
**JLC already placed (confirmed from the received-board photo):** 32× PC817B optos (U4–U35), 6× G5LE-14 **5 VDC** relays (K1–K6), 3× MCP23017 (U1–U3), NE555 (U36), the 100 µF electrolytic (C11), and all SOT-23/0805 parts.

**Your hand-solder set (all currently empty):** A1 (Pico), U37 (TMA-0505S), and connectors J1–J11, J13, J14. **J12 / M1 stays DNP — leave the 7th relay spot empty.**

## TL;DR — the safe path (full detail in the sections below)
**Solder power-critical-first and verify each rail as you create it — don't stuff the whole board then power once.**

1. **J2** (Phoenix 1715734) → 5 V in → **TP1 `VCC_5V` ≈ 4.6–4.8 V**
2. **A1** (Pico SC0915) → **TP3 `VCC_3V3` ≈ 3.3 V**
3. **U37** (TMA 0505S) → **TP4 `FIELD_WET_V` ≈ 5 V** AND **TP5 `FIELD_GND` OPEN to TP2 `GND`** (isolation proof)
4. **J1** (CNC Tech 3020-20-0100-00) → Pi link
5. **J14** (1843622) → safety loop, then **J6–J11**, **J3/J4/J5**, **J13**

**Four board-killers:**
- **U37 polarity** — match pin 1 to silk, **never flip** (it's the isolation barrier).
- **A1 Pico** — Micro-USB end overhangs the board edge per silk.
- **Before power** — check for fine-pitch bridges (3× SOIC-28 MCP, SOIC-8 NE555) and **no short** `VCC_5V`→`GND` / `VCC_3V3`→`GND`. Bench supply current-limited to ~500 mA so a bridge trips the limit, not a trace.
- **ESD** — wrist strap on for A1 + U37.

**Firmware:** the flashable `.uf2` is already built at `firmware/rp2040/build/wsl_phase8b_rp2040.uf2` (BOOTSEL drag-drop).

## Contents
1. Safety, ESD & Go/No-Go
2. Solder Order & Technique
3. Part-to-Silkscreen Map & Orientation
4. Connector Pinouts (J1–J14)
5. First Power & Test-Point Verification (the §12.9 sequence)
6. Troubleshooting

---

## Safety, ESD & Go/No-Go

> **Read this whole section before you apply power.** It is short on purpose, and every rule here is enforced by the board's hardware — not by your discipline alone. The one thing it asks of you is to bring the board up in *order* and to *stop* the moment a stage doesn't pass.

### S.0 What this bench session actually is — and the one risk you DON'T have

This board is on your bench. **No pinsetter is connected.** J6–J11 (the relay motion outputs) land in empty Phoenix screw terminals; J14's interlock loops are jumpered with wire, not wired into a machine; the camera/cams/grippers are not present. There is therefore **no machine-motion hazard in this session at all** — nothing can sweep, no table can drop, nothing can crush a hand. The cutover sections of the manual (§19, §21.3) are written around lockout/tagout and a machine that "moves and bites"; **none of that applies here.** This is **pure logic-only bench bring-up** (`21_bringup-cutover.md` §21.2: *"on a workbench, nowhere near a machine … with zero risk"*).

The only two hazards in this session are **to the board, not to you**:

1. **ESD** — A1 (the Pico) and U37 (the TRACO DC/DC) are the static-sensitive hand-solder parts. The MCP23017s, optos, NE555, and FETs are already placed and survived JLC's line, but you'll be handling the whole board.
2. **Solder shorts** — a bridge on a fine-pitch IC or a backwards electrolytic/diode can short a rail the instant you power up. The pre-power inspection (S.2) is what catches these *before* they let smoke out.

### S.1 Understand WHY the relays stay silent — the relay-enable rail (so you don't chase a "dead" board)

The single most important thing to internalize before you power up: **on a correctly-built board, the motion relays K1–K6 will NOT click when you first apply 5 V, and that is correct, not a fault.** If you don't understand this you will waste an hour "debugging" a board that is working perfectly.

Every motion relay coil hangs off a gated supply called `RELAY_ENABLE_RAIL` (test point **TP16**), *not* directly off 5 V (`06_board-power.md` §6.5; `12_channel-maps.md` §12.11). That rail is the drain of a P-channel pass-FET (**Q14**, AO3401A) and it is live **only when a hardware AND of six independent conditions is ALL true at once** (`19_safety-architecture.md` §19.2.5; `21_bringup-cutover.md` §21.1). Software cannot bypass any of them. Every condition's default state is **false/open** — the board is **fail-open by construction** (`22_troubleshooting.md` §22.0 item 6: *"a dead rail during diagnosis is the safe state, not necessarily a fault."*).

The six conditions, and why each is dead on a freshly-powered bare board:

| # | Condition | Source | Default state on a cold board | Why it's false at first power-up |
|---|---|---|---|---|
| 1 | **Watchdog OK** | NE555 (U36) kicked by the Pi on `WDOG_KICK` (J1 pin 7) → Q13 | false | No Pi kicking yet → NE555 times out → Q13 off |
| 2 | **Arm OK** | Pi `ARM_PERMIT` (J1 pin 8) → Q15 | false (R108 100k base pulldown) | Pi hasn't asserted ARM |
| 3 | **RP2040 OK** | Pico `GP2` (`RP2040_OK`, J1 pin 13) → Q16 | false (R110 100k pulldown; GP2 Hi-Z on reset) | Pico not booted / GP2 Hi-Z |
| 4 | **Cam-stop OK** | folds into #3 (firmware drives GP2 LOW on a cam-stop fault) | false | same path as #3 — *not a separate transistor* |
| 5 | **TB/SC interlock** | external NC loop on J14 pins **1↔2** | open | nothing wired across J14 |
| 6 | **Stop/CIS/master chain** | external NC loop on J14 pins **3↔4** | open | nothing wired across J14 |

Two structural facts (verified against `block_rail()`, per `19_safety-architecture.md` §19.2.5 and `22_troubleshooting.md` §22.4.2):

- **Conditions 5 & 6 are NC loops in series with the FET *source*.** +5 V enters J14 pin 1 → must traverse the closed TB/SC loop (1→2) → cross the on-board jumper (`SAFE_TBSC_RETURN`, J14 pin 2 = pin 3) → traverse the closed Stop/CIS loop (3→4, `SAFE_STOP_RETURN`) → only then reach Q14's source. **Break either loop and no gate state on earth can turn the rail on.**
- **Conditions 1, 2, 3(=4) are a series transistor stack on the FET *gate*.** The gate (`RAIL_GATE`) is held up to the source by R106 (100k) — off by default. Q15 (ARM) · Q16 (RP2040_OK) · Q13 (watchdog) must **all three conduct** to pull the gate low and turn the P-FET on. Any one open → rail dead.

> **Bench consequence:** to make the rail come up on the bench you must *deliberately* satisfy all six — including jumpering J14 1–2 and 3–4 closed (S.3 stage E). **Do NOT jumper J14 pin 1→4** to "make it work" — that bypasses both interlocks and is the one bench shortcut that defeats the whole safety model (`11_connector-pinouts.md` §11.9). On a machine this rail is what guarantees the board can only ever *fail to permit* motion, never *cause* it; on the bench it's just the thing you prove drops cleanly six different ways.

### S.2 ESD handling for the hand-solder parts (A1, U37)

A1 (Raspberry Pi Pico SC0915) and U37 (TRACO TMA-0505S) are the parts you'll be soldering. The CLAUDE.md project rule and the Pi-GPIO memory both stress static discipline; for the DC/DC and the Pico:

1. **Wrist strap + grounded mat.** Wear an ESD wrist strap clipped to a grounded mat (or to the bench's ground point). The Pico's castellated module and the DC/DC's exposed SIP pins are both handled directly.
2. **Keep parts in their ESD bags / trays until the moment you place them.** Don't fan them out on a cloth bench surface.
3. **Iron must be ESD-safe / grounded-tip.** A floating-tip iron can dump static into the part you're soldering.
4. **Touch the board's GND (TP2) before handling.** Equalize potential with the board before each handling session.
5. **No carpet, no synthetic clothing static.** Standard bench hygiene; the WSL Pi-voltage memory already flags 3.3V-only sensitivity — treat the whole logic side as static-sensitive.
6. **Use the castellated SC0915, NOT a Pico H/WH with header pins** (`hand-solder-bom.csv` A1 note; `22_troubleshooting.md` §22.9.1). A headered Pico will not fit the A1 footprint.

### S.3 Pre-power inspection checklist (do this BEFORE applying 5 V at J2)

Bridges and reversed polarized parts are the failure mode that kills a board on first power. Inspect under magnification, both sides, before the supply touches J2. The recommended solder order is **J2 → A1 → U37 → J1 → J14 → J6-J11 → J3/J4/J5 → J13**; run this inspection on whatever you've placed so far, and re-run the relevant rows after each new part.

**(a) Fine-pitch IC bridges — the 3× MCP23017 (SOIC-28W) + the NE555 (SOIC-8):**

- [ ] **U1, U2, U3 (MCP23017, SOIC-28W, P1.27mm):** sight down each side of all three for solder bridges between adjacent legs. These are 1.27 mm pitch — the most likely place for a JLC reflow whisker. A bridge on the I²C or address-strap pins will NAK the bus.
- [ ] **U36 (NE555DR, SOIC-8):** same — check all 8 legs. A short here corrupts the watchdog timing or VCC.
- [ ] Confirm **pin-1 orientation** on all four: the dot/notch on each IC matches the silk pin-1 datum. (JLC placed them, but verify — a reflowed-rotated part is rare but board-killing.)
- [ ] Glance the SOT-23 FET/BJT cluster around the rail (Q12/Q13 AO3400A, Q14 AO3401A, Q15/Q16 MMBT3904): **do not assume N-ch and P-ch are interchangeable** — Q14 is the *P-channel* AO3401A rail pass-FET; Q12/Q13 are *N-channel* AO3400A; they look identical in SOT-23 (`22_troubleshooting.md` §22.9.2 critical note). You can't fix a swap (JLC placed them) but flag it if you find one — it would explain a rail that never comes up.

**(b) C11 electrolytic polarity (the 100 µF / 16 V watchdog timing cap):**

- [ ] **C11** is the only polarized electrolytic and it sets the NE555 monostable timeout (`C_WDOG_TIMING`, 100 µF/16 V, per `21_bringup-cutover.md` §21.2.1 step 4 and `12_channel-maps.md` §12.10). Confirm the **minus stripe / short leg faces the silk's negative mark.** Backwards = it bulges/vents on power and the watchdog timing is wrong. JLC placed it, but it's the highest-consequence polarized part on the board — eyeball it.
- [ ] **D17 (SS14 Schottky, SMA):** confirm the cathode band matches the silk. Anode → `VCC_5V_RAW`, cathode → `VCC_5V` (`06_board-power.md` §6.2.2). Backwards = no 5 V reaches the board at all (and is also your reverse-polarity guard, so a backwards D17 defeats that protection).
- [ ] **D2-class flyback/steering diodes** (1N4148WS, SOD-323) — cathode bands per silk if you're spot-checking; JLC-placed.

**(c) Opto / relay / IC pin-1 orientation:**

- [ ] **U4–U35 (32× PC817B, DIP-4):** scan that pin-1 (the LED-anode corner, marked by the chamfer/dot) faces the silk pin-1 on all 32. A reversed opto won't conduct the right way. (JLC-placed, but 32 parts is 32 chances.)
- [ ] **K1–K6 (G5LE-14 relays):** seated flat, correct orientation per silk outline. **Confirm these are the 5 VDC coil variant** — the BOM is explicit: *do not substitute 9V/12V/24V coil* (`06_board-power.md` §6.5; `22_troubleshooting.md` §22.9.2). **K7/J12 (M1) is DNP — confirm it is empty.**
- [ ] **A1 (Pico)** when fitted: castellations fully wetted, module flat, pin-1 / USB-end matches the silk "J1 PI / LOGIC / SAFETY" datum.
- [ ] **U37 (TMA-0505S)** when fitted: pin-1 to silk. This part is *isolated* — getting it backwards or bridging primary↔secondary defeats the FIELD_GND isolation barrier (see (d)).

**(d) Bottom side clean + isolation intact:**

- [ ] Flux residue cleaned, **no stray solder balls** on either side (a loose ball bridging LOGIC↔FIELD across the keepout gutter is the worst case).
- [ ] **`FIELD_GND` must share ZERO nodes with `GND`.** With the board unpowered, meter continuity between **TP5 (`FIELD_GND`)** and **TP2 (`GND`)** → must read **OPEN / no continuity** (`06_board-power.md` §6.9; `22_troubleshooting.md` §22.0 item 4). If they beep continuous, you have a solder bridge across the isolation barrier or U37 fitted wrong — **STOP and fix before powering**. Do this check *after* fitting U37, and never bond the two grounds with a probe clip or scope ground during testing.
- [ ] Quick rail-short check, board unpowered: meter resistance **TP1 (`VCC_5V`) → TP2 (`GND`)** and **TP3 (`VCC_3V3`) → TP2**. A dead-short (near 0 Ω) on either means a bridge — find it before applying power. (Expect tens of kΩ to a few hundred Ω, not 0 Ω.)

### S.4 The per-stage GO / NO-GO gates

Bring the board up in the documented order: **power rails → I²C enumerate → RP2040 boot → watchdog drop → arm drop → interlock drop → relays → inputs** (`06_board-power.md` §6.8; `22_troubleshooting.md` §22.0 item 5; firmware README §"Bench bring-up"). **The governing rule: each stage gates the next. If a rail check fails, STOP and fix it before adding the next part — do not stack a second fault on top of an unverified rail** (`21_bringup-cutover.md` §21.2.1: *"each step gates the next"*).

Use the test pads as your meter taps — **probe TPx, not IC legs**. Net-per-TP map (`21_bringup-cutover.md` §21.2.2 / `11_connector-pinouts.md` §11.10):

| TP | Net | TP | Net |
|---|---|---|---|
| TP1 | `VCC_5V` | TP9 | `WDOG_TIMING_NODE` |
| TP2 | `GND` | TP10 | `NE555_TRIG` |
| TP3 | `VCC_3V3` | TP11 | `NE555_OUT` |
| TP4 | `FIELD_WET_V` | TP12 | `WDOG_OK_PULLDOWN` |
| TP5 | `FIELD_GND` | TP13 | `ARM_PERMIT` |
| TP6 | `I2C_SDA` | TP14 | `RP2040_OK` |
| TP7 | `I2C_SCL` | TP15 | `SAFE_STOP_RETURN` |
| TP8 | `WDOG_KICK` | **TP16** | **`RELAY_ENABLE_RAIL`** ← the single most useful tap |

**Gate-by-gate "what pass looks like" (probe values from `06_board-power.md` §6.9 and `21_bringup-cutover.md` §21.2.1):**

| Stage | What you do | GO (pass) | NO-GO → STOP and… |
|---|---|---|---|
| **A. Rails** | 5 V into **J2** pin 1 (`VCC_5V_RAW`), GND on pins 2/3. (J2 soldered first.) | **TP1 ≈ 4.6–4.8 V** (5 V minus SS14 Vf). **TP3 ≈ 3.3 V** *only after A1 fitted* (Pico sources 3V3). **TP4 ≈ 5 V isolated** *only after U37 fitted*. **TP5↔TP2 = OPEN** (isolation). No part hot to the touch. | Rail wrong/short → check D17 orientation, U37 fit, the S.3(d) short check, A1 fit. **Do not fit the next part on a bad rail.** Note: TP3 dead before A1 is fitted is *expected* — there is no 3.3 V until the Pico is on (`06_board-power.md` §6.3). |
| **B. I²C enumerate** | Pi connected via **J1**; scan the board's I²C bus. | All **3× MCP23017** answer: **0x20 (U1, IN-A), 0x21 (U2, IN-B), 0x22 (U3, OUT-A)** (`12_channel-maps.md` §12.3). | A chip NAKs → re-check that chip's solder/bridges (S.3a), the 4.7k pull-ups (R1/R2), and the A0/A1/A2 address straps. |
| **C. RP2040 boot** | Flash `firmware/rp2040/build/wsl_phase8b_rp2040.uf2` (BOOTSEL drag-drop), power up; watch UART (J1 pins 5/6, 115200-8N1). | A `boot` line, then `hb` heartbeats at ~4 Hz with `ok:1`. After ~200 ms (`BOOT_SETTLE_MS`) **TP14 (`RP2040_OK`/GP2) goes HIGH** (`rp_ok:1`). | No boot/hb → check Pico solder, UART crossover (Pi TX→Pico GP1, Pico GP0→Pi RX — *crossover is done on the PCB, wire the ribbon straight*, `11_connector-pinouts.md` §11.2). GP2 stuck LOW → firmware not healthy / a latched fault. |
| **D. Watchdog drop** | With the rail armed on the bench-safe path (all six conditions satisfied — see E), **stop kicking `WDOG_KICK`**. | After the NE555 timeout, **TP16 drops to ~0 V.** Watch the transition at TP11 (`NE555_OUT`) / TP12 (`WDOG_OK_PULLDOWN`). | Rail won't drop → the watchdog AND-rung isn't gating. Check the NE555 RC (R100 100k, C11 100µF), the trigger pull-up (10k), Q13. **(VERIFY: NE555 timeout is bench-measured, NOT assumed — design RC ≈ 11 s but it's a retrigger topology; measure it, don't trust ~10 s** — `19_safety-architecture.md` §19.2.4 / `22_troubleshooting.md` §22.7.) |
| **E. Arm + interlock drops** | First satisfy all six conditions so the rail is live (kick the watchdog, assert ARM, GP2 high, and **jumper J14 1–2 and 3–4 closed**) → confirm **TP16 ≈ VCC_5V**. Then knock out one condition at a time: de-assert `ARM_PERMIT` (TP13 low); then open the **TB/SC** loop (J14 1–2); then open the **Stop/CIS** loop (J14 3–4). | **TP16 drops to ~0 V on EACH** independent knock-out. TP15 (`SAFE_STOP_RETURN`) goes open/low when a J14 loop opens. | Any one fails to drop the rail → that safety condition is not gating. **This is the heart of the safety proof — do not move on until all of them drop the rail independently.** Confirm the J14 jumpers were actually closed for the "live" baseline; check Q14 (rail pass-FET), Q15 (ARM AND). |
| **F. Each relay (dummy load)** | Re-establish all rail conditions. Command each motion relay (**S, T, SP, BE, M, M2** = K1–K6) in turn via MCP OUT-A (0x22). Put a dummy load (lamp/resistor) across that relay's J6–J11 contact pair. | Relay clicks; its COM-NO contact closes the dummy load; **the load drops the instant you drop the rail** (proving the rail gates the coil, not just the command). **M1 (K7/J12) is DNP — not tested.** | Relay won't fire with rail up → check the per-relay NPN (Q1–Q6), the OUT-A bit↔relay map (S=(0,0) … M2=(0,5); M2 is bit 5 *before* M1 — `12_channel-maps.md` §12.7), the flyback. |
| **G. Inputs** | Exercise each opto: wet a fast input pin (J3) to `FIELD_GND`; wet each slow input (J4/J5). | The matching RP2040 fast-input edge (`cam`/`ball` over UART) or MCP bit flips. **Optos are active-LOW** — a closed field contact pulls the logic pin LOW (`12_channel-maps.md` §12.2.2). | No flip → check the PC817 (U4–U35), `Rin` 2.2k, the 10k logic pull-up to 3V3, and that `FIELD_WET_V` (TP4) is present (needs U37). |

**Pass = stages A–G all green and logged.** Only then is the board a candidate for the cutover work in §21.3 (gate **G1**) — which is a *separate, future, at-a-machine* operation, not part of this bench session.

> **Note on the cam-stop sub-test (firmware caveat).** The shipped firmware provides RP2040 *health* + the *motion max-run* backstop (`MAX_MOTION_MS` = 8000 ms). You can prove the GP2→rail drop path directly (reset/halt the Pico → TP16 drops) and the max-run sense (mark a motor RUN, let it exceed 8 s → fault → TP16 drops). True **per-cam-edge cam-stop overrun** enforcement ships **default OFF** (v1.1 flags gated until per-cam edge→angle polarity is field-captured at cutover — firmware README ⛔ banner; `19_safety-architecture.md` §19.3.4). That is a cutover-day item; it does **not** block your logic-only bench bring-up.

### S.5 The one rule to carry through the whole session

**If a rail check fails, STOP and fix it before adding the next part.** Don't fit U37 onto an unverified 5 V rail; don't flash the Pico onto a board whose I²C won't enumerate; don't command a relay before TP16 has been proven to come up *and* drop six different ways. The board is designed to fail open — a dead rail mid-bring-up is the safe, expected state, not necessarily a defect (`22_troubleshooting.md` §22.0 item 6). Your job at the bench is to prove, stage by stage, that it comes *up* when all conditions are met and goes *dead* the instant any one is removed.

---

**Source files grounding this section** (all absolute):
- `C:\Users\Dylan DeYoung\wsl-lane-nodes\docs\manual_src\19_safety-architecture.md` (§19.2.5 six-condition rail, §19.2.6 welded-contact, §19.3.4 v1.1 cam-stop deferral)
- `C:\Users\Dylan DeYoung\wsl-lane-nodes\docs\manual_src\21_bringup-cutover.md` (§21.1 rail summary, §21.2.1 bring-up steps, §21.2.2 TP map)
- `C:\Users\Dylan DeYoung\wsl-lane-nodes\docs\manual_src\06_board-power.md` (§6.5 rail topology, §6.8 fit order, §6.9 power TP expected values)
- `C:\Users\Dylan DeYoung\wsl-lane-nodes\docs\manual_src\11_connector-pinouts.md` (§11.2 J1, §11.9 J14, §11.10 TP cross-ref)
- `C:\Users\Dylan DeYoung\wsl-lane-nodes\docs\manual_src\12_channel-maps.md` (§12.3 MCP addrs, §12.7 OUT-A map, §12.10 watchdog timing)
- `C:\Users\Dylan DeYoung\wsl-lane-nodes\docs\manual_src\22_troubleshooting.md` (§22.0 safe handling, §22.4.2 six conditions, §22.9.2 critical-substitution notes)
- `C:\Users\Dylan DeYoung\wsl-lane-nodes\firmware\rp2040\README.md` (safety model, bench bring-up, v1.1 flags-OFF banner; `.uf2` at `firmware\rp2040\build\wsl_phase8b_rp2040.uf2`)
- `C:\Users\Dylan DeYoung\wsl-lane-nodes\kicad\fab_revB_routed_manual\assembly\wsl-phase8b-revB-hand-solder-bom.csv` (A1/U37/J-connector parts + critical notes)

**Flagged for verification at the bench (carried from the source docs):**
- **NE555 watchdog timeout is bench-MEASURED, not assumed** — design RC ≈ 11 s but it's a retrigger topology; do not assume ~10 s (§19.2.4 / §22.7).
- **C11 is 100 µF / 16 V electrolytic, polarized** — verify the minus stripe against silk before power (highest-consequence polarized part).
- **Q14 = P-channel AO3401A vs Q12/Q13 = N-channel AO3400A** — visually identical SOT-23; a swap (JLC-placed) would explain a rail that never comes up.
- **Pin-1 datum for A1 (Pico) and U37 (TMA-0505S)** — confirm against the silk before/after soldering; U37 backwards also defeats FIELD_GND isolation.

---

## Solder Order & Technique

This is the hand-solder pass on a JLC-assembled Rev-B board (`A1`, `U37`, and the Phoenix/IDC connectors `J1–J11`, `J13`, `J14` are the empty parts; `J12`/`M1` stay DNP — leave it empty). Work the order **power-critical-first and verify each rail as you create it.** Do **not** stuff the whole board and then power it once — the whole point of the staging is that if a rail comes up wrong you know exactly which part you just fitted caused it, on an otherwise-bare board, instead of hunting across 14 connectors and two actives at the end.
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

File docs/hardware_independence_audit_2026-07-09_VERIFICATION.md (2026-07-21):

# Hardware Independence Audit — Independent Verification

**Verification date:** 2026-07-09
**Verifies:** `docs/hardware_independence_audit_2026-07-09.md` (Codex audit, 58 findings)
**Method:** 23-agent adversarial re-check (Fable) against the exact commits Codex used —
wsl-lane-nodes `82feed6`, WSL Systems `4732e3b` — plus re-execution of all 6 of the audit's
reproducible claims. Read-only; no source, firmware, PCB, or config was modified.

---

## Bottom line

The Codex audit is **legitimate and accurate**. Of 58 findings: **53 CONFIRMED, 5 PARTIAL
(overstated, not wrong), 0 REFUTED.** All 6 executable claims reproduced byte-for-byte. The
NO-GO verdict for live Track-B cutover is **correct and should stand.**

Two framing corrections apply to how the findings are acted on:

1. **Almost nothing is an *active* hazard today.** The rev-B board's relays are dead (footprint
   bug), no v1.1.1 firmware is flashed, and no machine is live. The audit's severity labels are
   calibrated to a live machine that does not yet exist — they are correct as **cutover release
   gates**, not as present dangers. The one exception is the credential (§ Credential below),
   which is exposed now, independent of the hardware timeline.

2. **~75% of the flagship findings were already documented open gates**, mostly from the
   2026-06-27 Fable review and the 2026-06-09 audit, or in the source comments themselves. Of 21
   headline findings novelty-checked: **9 KNOWN, 7 PARTIALLY_KNOWN, 5 genuinely NEW.** The audit
   is a valuable re-consolidation of the existing backlog into one clean gate document, but it
   presents known items as fresh discovery without crediting existing tracking.

| Verdict | Count |
|---|---:|
| CONFIRMED | 53 |
| PARTIAL (overstated) | 5 |
| REFUTED | 0 |
| **Total** | **58** |

Executable claims re-run: **6 / 6 CONFIRMED.**

---

## The 5 genuinely NEW bugs (the audit's real value-add)

Not present in any prior review doc; worth engineering attention before bench-live work.

| ID | Sev | What's new | Why it matters |
|---|---|---|---|
| **C-02** | Crit | `controller_io.py:120-124` caches the OLAT bit **before** the I2C write; a NACK on a de-energize is consumed as the one-shot stop, and a later unrelated write re-asserts the stale bit | **Priority.** A *failed energize* path yields uncommanded motor energize with FSM in READY, where neither `MAX_MOTION_S` nor the firmware backstop covers it. Cache/hardware divergence reproduced. |
| **H-02** | High | `cycle_control_8270.py:216-219` resets the motion timer on **every** FSM state transition | Falsifies the "8s per-motor backstop" the source comment (`:67`) claims — a table energized continuously across TABLE_DETECT→RUNTHROUGH→TABLE_FINISH ran **23.7s** with no timeout. |
| **H-04** | High | Unhealthy branch at `controller_daemon.py:306-326` returns before `_slow_edges()`, so PBZ can never emit CLEAR after a firmware-latched fault | Breaks the code's own recovery contract (`:152-156`) → operator-unrecoverable lane, invites improvised resets. Fails safe (motors off) but no clean recovery. |
| **H-08** | High | Q14 (AO3401A rail pass-FET) is a single unmonitored point; a drain-source short bypasses watchdog+ARM+RP_OK, and nothing reads back `RELAY_ENABLE_RAIL` | Manual markets the rail as "non-bypassable" (`10_watchdog-rail.md:153-156`) while analyzing only the fail-open direction. No rail-drop feedback. |
| **H-19** | High | `provision_wsl_tasks.ps1:43` installs a **nonexistent** flat `lane_node_server.py` path with global Python; `requirements.txt` lacks `websockets` | A reprovision produces a lane server that can't start; the Unregister-then-Register (`:51-52`) replaces a correct manual task; `deploy.ps1` kills the running server and the smoke test stays green (never checks port 8766). |

C-02 and H-02 both directly falsify safety claims made in the code's own comments.

---

## The 5 PARTIAL findings (Codex overstated — corrections)

- **M-01** (MCP init order) — **misattributes the exposure.** The brief output window comes from
  *register retention* across a warm restart, not the IODIR-before-OLAT ordering; the ordering
  only delays remediation by ~4 sub-ms writes, and the rail is nominally down during init anyway.
  Reorder-OLAT-first is fine hardening, but it is not the mechanism claimed. → hardening, not a
  live init exposure.

- **C-09** (live-default) — code is confirmed live-by-default, but "a reboot alone moves
  hardware" is wrong: the daemon boots **disarmed into MANUAL_INTERVENTION** and the systemd unit
  ships **disabled** until §12.9 sign-off. It is a documented deliberate decision (review #52,
  `controller_daemon.py:71-72` "flip into a hard gate at/after §12.9"), not an unnoticed defect.
  Critical-as-release-gate is fair; critical-as-live-hazard is not.

- **H-24** (TMA0505S isolation) — real doc bug (`06_board-power.md:176` says ~1.5kV, but the
  selected part is 1000VDC **functional**, and BOM requires ≥1.5kV), but the docs never claim
  "protective" isolation — that framing is the auditor's — and `:176` already self-flags the
  number with a VERIFY note. → spec-number correction + part-vs-BOM mismatch, not a High.

- **M-18** (pair validation) — non-adjacent pairing is an **intentional** desk feature ("link two
  lanes for parties", `desk.html:1521-1526`); the recommendation would break it. The team-to-lane
  sort reversal is real but **unreachable** in the deployed config (the sole schedule writer
  `genRoundRobin` always emits ascending lanes). The stronger real defect the audit *missed*:
  transfer at `wsl_api.py:1084-1088` silently re-pairs to the adjacent lane. → low-medium.

- **H-22** (relay suppression) — accurate that load/suppression is unqualified, but "a guide says
  the 10A rating makes measurement optional" is not in the docs — every "10A is ample" line sits
  inside a VERIFY/open-item marker, and "keep suppression DNP until engineered" (the audit's own
  recommendation) is already the shipped state. → project-tracked gated open item, not a High gap.

---
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

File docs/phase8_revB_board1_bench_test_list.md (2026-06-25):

---
title: "WSL Phase 8 rev-B Board #1 — Bench Test List"
---

# WSL Phase 8 rev-B — Board #1 Bench Test List

| Field | Value |  | Field | Value |
|---|---|---|---|---|
| Board ID | __________ | | Date | __________ |
| Tester | __________ | | DMM | __________ |
| Bench supply | ______ V / ______ mA limit | | | |

**Grounded from the live netlist.** Pair this with the **probe-locations map (page 1)** and the connector pin-number map. Do Phases 0–2 fully **before any power**. Meter notes: shorts on continuity/low-Ω ("NOT shorted" = reads high, not a steady beep — caps make rail readings *climb*, that's normal). Continuity = beep ≈ 0 Ω; probe **pin metal**, not flux/plastic. **Logic → reference TP2 (GND);
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

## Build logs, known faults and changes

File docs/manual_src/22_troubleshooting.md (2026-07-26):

## 22. Troubleshooting, Maintenance & Spares

> **Read §22.0 (safe handling) before touching anything.** This system commands AC
> motors that move heavy mechanism near people. Almost every fault below can be
> diagnosed at the bench or from a log; the few that require reaching into the
> machine require lockout first. When in doubt, the safe state is **manual desk
> scoring + the original controller still cycling the pinsetter** — Track A is
> read-only and Track B is not yet cleared for live machines, so you can always
> fall back without any machine risk.

This section is the field-service guide: **symptom → likely cause → fix**, plus
the maintenance routine, the spares list, and the safe-handling rules. It assumes
the architecture from the earlier sections. Cross-references point to:

- **§2, System Architecture & Signal Chain** — the end-to-end picture.
- **§5, Rev-B Controller Board: Overview, Domains & Isolation** and **§6, Rev-B Power Architecture** — board layout, the three electrical domains, power rails.
- **§7, Rev-B Logic: RP2040 Co-processor + MCP23017 Expanders + I2C** and **§8, Rev-B Field Inputs: PC817 Opto-isolators** — the logic + input front-ends.
- **§9, Rev-B Machine Outputs: G5LE Relays** — the relay output stage.
- **§10, Rev-B Safety Hardware: NE555 Watchdog + Relay-Enable Rail** — the
  board-side permissions, Candidate-C source jumper, and test pads (the single most
  important section for "relays won't energize").
- **§11, Rev-B Connector Pinouts (J1–J14)** and **§12, Rev-B Channel Maps** — connector pinouts and the GPIO/MCP bit maps.
- **§14, Machine Interface: C1/C2A Connectors & the Adapter Harness** — machine-side wiring.

Every fact here is grounded in the live files: `firmware/rp2040/config.h` +
`firmware/rp2040/README.md` (RP2040 pins/timing/protocol), `lane_node/controller_daemon.py`
+ `lane_node/controller_io.py` + `lane_node/rp2040_link.py` + `lane_node/cycle_control_8270.py`
(the Pi-side control software), `docs/phase8b_pcb_revB_spec.md` §4 (the safety-rail
contract), `docs/phase8_trackA_golive_runbook.md` (scoring go-live + failure
cheat-sheet), and the assembly BOM
(`kicad/fab_revB_routed_manual/assembly/wsl-phase8b-revB-jlc-standard-pcba-bom.csv`).

---

### 22.0 Safe handling — read before every job

These are non-negotiable. They come straight from the design contract
(`docs/phase8b_pcb_revB_spec.md` "Non-negotiable safety rule", §4.5) and the
firmware safety model.

1. **The controller board is never the only safety device.** The pilot machine's
   upstream **Stop switch → master circuit breaker** chain, the **TB/SC collision
   interlock**, and the motors' **regenerative
   braking** all stay in hardware, independent of any software. Do not defeat,
   jumper-out, or "temporarily bypass" any of them. OEM documents also describe
   C.I.S.; physical inspection found no such device or wiring on lanes 21/22.

2. **Lockout/tagout before touching the machine mechanism or its wiring.** The
   relay-enable rail removes *coil drive*; it **cannot open a relay contact that
   has welded closed** (§10.6, spec §4.5). The only guaranteed kill is the
   **rear-panel master circuit breaker** (cut by the installed Stop chain). Cut and
   lock the master breaker before reaching into the pinsetter. Track-B bench and
   cutover work is explicitly **"on a LOCKED-OUT / off machine only"**
   (`firmware/rp2040/README.md` §"Bench bring-up"; spec §12.9).

3. **GPIO is 3.3 V only.** The RP2040 and the MCP23017s run at **3.3 V** (the
   MCP23017s are on 3.3 V specifically for Pi-safe I²C — spec §6.1, §8.1). **Never
   wire a machine voltage (24 VAC, 15 VDC, etc.) to a Pi/RP2040/MCP pin.** Every
   machine input must cross a **PC817B opto** first (§8); every machine output
   crosses a **G5LE relay contact** (§9). The opto logic sides and MCP inputs are
   already 3.3 V and Pi-safe by design — keep them that way. If you add a test
   front-end, use opto isolation or a contact-to-a-reference scheme, never a
   direct tap.

4. **Logic ground (GND) and field ground (FIELD_GND) are intentionally
   separate** and share **zero nodes** (the isolation barrier — §5, §6). Do not
   bond them with a probe clip, a scope ground, or a "temporary" jumper. The
   isolated field-wetting supply (TRACO TMA-0505S, ref **U37**) exists precisely
   to keep a machine-side fault from backfeeding the Pi.

5. **Bring up power before signals, and bring up the rail last.** The documented
   bench order (§10.8, spec §12.9, firmware README) is: power rails → I²C
   enumerate → RP2040 boot + heartbeat → **watchdog drop** → **arm drop** →
   **J14 source-position drops** → each relay with a *dummy load* → input
   front-ends → motion-timeout / qualified cam-stop drop → **only then** the
   machine harness. Candidate-C TB/SC protection is proven separately at G3 by
   commanding S and T and forcing both OEM levers BACK/open.

6. **The board fails open by construction.** On loss of logic power, watchdog
   kick, RP2040 health, arm permission, or an implemented source loop, its relay
   coils go dead. Separately, the preserved OEM TB/SC ladder must block S/T when
   both levers are BACK/open. If you are unsure of a board's state, the *correct*
   default is motion-dead — so a "dead" rail during diagnosis is the safe
   condition, not necessarily a fault.

---

### 22.1 Fast triage — which subsystem is failing?

Decide which of the three independent subsystems is misbehaving before you dig in.
They fail independently and have different fixes:

| You observe… | Subsystem | Go to |
|---|---|---|
| A lane stops scoring, or scores wrong, but the pinsetter still cycles normally | **Track A — camera scoring** (read-only; never affects the machine) | §22.2 |
| The lane "went dark" after a power blip / reboot — no scoring node at all | **Pi service / provisioning** | §22.3 |
| (Track B, bench/cutover) relays won't energize / the rail is dead | **Safety rail** (an implemented permission/source position is open) | §22.4 |
| (Track B) a motor runs and then the whole board faults; relays drop | **Motion-timeout / cam-stop** | §22.5 |
| (Track B) cam/ball events missing, RP2040 reported unhealthy | **RP2040 link / UART** | §22.6 |

> **Track A vs Track B blast radius.** A Track-A (scoring) fault can never move the
> machine — the existing controller is still cycling the pinsetter and the code
> auto-falls-back to manual desk scoring (`docs/phase8_trackA_golive_runbook.md`,
> "Safety/blast-radius"; `lane_node/lane_node.py` `_init_camera()` /
> `_settle_capture_emit()`). Track-B faults are about *machine control* and are why
> the layered safety architecture exists.

---

### 22.2 Track A — camera scoring faults (read-only, safe)

Track A taps the QubicaAMF **T-Camera** composite video through the **VIXLW USB
dongle** into the Pi, and detects standing pins by **difference-from-empty**
(§2, §18/Track A). It is read-only with respect to the machine and auto-falls back
to manual on any failure. The authoritative procedure for all of this is
`docs/phase8_trackA_golive_runbook.md`; this is the service-desk condensation of
its failure cheat-sheet plus the exact code paths.

#### 22.2.1 "detector NOT ready" / lane silently falls back to manual

**Symptom (in `journalctl -u lane-node`):**
```
Camera mode but detector NOT ready (no empty ref / cv2).
Balls will fall back to manual desk scoring until fixed.
```
(emitted by `lane_node/lane_node.py` `_init_camera()` when `PairCamera.ready` is
false). You will also see `_settle_capture_emit()` log `camera yielded no mask ->
awaiting_manual (desk score)` per ball.

| Likely cause | Fix |
|---|---|
| **`empty_ref.png` missing or unreadable.** The detector compares each ball's frame to a stored cleared-deck reference; with none, it cannot detect. The file is gitignored — **each Pi captures its own** (it is *not* pulled by `git pull`). | Clear **both** decks (cycle 21 and 22 so all pins are swept), then on the Pi: `cd /home/pi/wsl-lane-nodes` → `.venv/bin/python3 lane_node/camera.py --capture-empty` (add `--device 1` if the dongle is `/dev/video1`). Saves `lane_node/empty_ref.png` (720×576). Verify non-zero size; ideally scp it off and eyeball that it really is an empty deck under normal lighting. Restart: `sudo systemctl restart lane-node`. Confirm the log now shows `Camera ready for lanes [21, 22] (settle=2.5s).` |
| **OpenCV/PyAV import failed (`cv2`).** `PairCamera` needs a capture backend. | `.venv/bin/python3 -c "import numpy, PIL, av; print('deps ok')"` — if `av` fails, `.venv/bin/pip install av` (or `pip install opencv-python`; either backend works). |

> **This is not dangerous.** "Detector not ready" means the lane simply scores
> manually at the desk via `POST /api/lane/N/score` — the pinsetter still runs.

#### 22.2.2 Black frame / `--test` always reads 0 or 1023 (mask never changes)

**Symptom:** `.venv/bin/python3 lane_node/camera.py --test` prints all-black, or the
per-deck mask is stuck at `0` (empty) or `0b1111111111` = `1023` (full rack)
regardless of what's actually standing.

| Likely cause | Fix |
|---|---|
| **Missing video ground on the camera tap** — the single most common hardware trap, identical to the original QubicaAMF tap. The composite tap is **Brown = video / Blue = ground**; the RCA shell must reach Blue (pin-8 ground). | Reseat the tap **ground** (RCA shell → Blue / pin-8). This is wiring, **not** a code bug. |
| **Dongle not enumerated** (no `/dev/video0`) | `ls -l /dev/video*` (expect ≥ `/dev/video0`); `v4l2-ctl --list-devices` should show a USB Video/UVC device. Reseat USB; check `dmesg`. If it enumerates as `/dev/video1`, set `WSL_LANE_CAMERA_DEVICE=1` on the service. |

#### 22.2.3 Scores are wrong but consistent

**Symptom:** detection runs, but a particular pin/spot is repeatedly misread (the
*same* error every time), not random flakiness.

| Likely cause | Fix |
|---|---|
| **Per-spot calibration** — that pin's region coordinate (`PIN_SPOTS_PX`) or the per-frame threshold is slightly off. Pins **2 & 3** are the homography-predicted spots (watch these first); the **right deck** is more oblique, so its margins are tighter. | This is a tuning item, not a redesign. Keep a tally of **detected vs actual** standing pins per ball; capture a couple of misread frames. The fix is a `PIN_SPOTS_PX` coordinate nudge or a `DET_THR` adjustment (calibration lives in `lane_node/pin_detect.py`). Send the tallies + frames to whoever owns the detector calibration. |
| **Whole-frame flakiness that tracks the house lighting** (lights on/off, sun) | Re-measure / bump `DET_THR`. The detector already drift-corrects for exposure, so this should be rare; last resort is an IR illuminator + IR-pass filter. |

#### 22.2.4 Nothing happens on a ball

| Likely cause | Fix |
|---|---|
| **DIELL ball detector not firing**, or the node is in the wrong mode | Watch the log for `GPIO: ball detected on lane N, mode=camera`. If that line never appears, the DIELL beam isn't tripping the input. If it appears but no score, confirm the mode is `camera` (see below). |
| **Wrong scoring mode** | `WSL_LANE_SCORING_MODE` must be `camera` for auto-scoring. `manual` = desk scores (ball event emitted with no `pin_mask`); `disabled` = log only. Default is `manual` (`lane_node/lane_node.py`). |

#### 22.2.5 Track A mode/tuning knobs (env vars on the `lane-node` service)

Set these via `sudo systemctl edit lane-node` (a drop-in survives reboot), then
`sudo systemctl restart lane-node`:

| Var | Default | Meaning |
|---|---|---|
| `WSL_LANE_SCORING_MODE` | `manual` | `camera` = auto-score; `manual` = desk scores; `disabled` = log only |
| `WSL_LANE_CAMERA_SETTLE_S` | `2.5` | seconds after DIELL fires before grabbing the frame (tune if catching the sweep or pins still rocking) |
| `WSL_LANE_CAMERA_DEVICE` | `0` | capture device index (`/dev/videoN`) |
| `WSL_LANE_CAMERA_STUB` | `0` | `1` = synthetic masks — **bench only, never on a live lane** |
| `WSL_LANE_SERVER_URL` | `ws://localhost:8765` | the WSL-SRV server (currently `ws://192.168.4.103:8765`) |

> **To abort Track A to manual instantly:** flip `WSL_LANE_SCORING_MODE=camera →
> manual` and `sudo systemctl restart lane-node` (or Ctrl-C the foreground daemon
> and relaunch without the env var). **No machine impact** — the lane keeps
> running; the desk scores via the existing flow.

#### 22.2.6 Server-side check (WSL-SRV)

The scoring **server** (`lane_node_server.py`) runs on WSL-SRV at **ports 8765
(WebSocket) + 8766 (HTTP)**. Health from any LAN machine:
```
curl http://192.168.4.103:8766/api/health
```
returns JSON with the connected node. The per-lane scoring display is
`http://192.168.4.103:8766/display?lane=N`. A manual correction is always available:
`POST /api/lane/N/score {pin_mask, foul?}`.

> **(VERIFY: WSL-SRV IP.)** The server IP is **192.168.4.103** as of the 2026-06-03
> eero router swap (the old `192.168.86.36` is dead), but the DHCP reservation was
> still a TODO in the runbook — **confirm the current WSL-SRV IP and that it is
> reserved on the eero** before relying on these URLs. (`docs/phase8_trackA_golive_runbook.md` banner.)

---

### 22.3 "Lane went dark after a power event" — service not enabled

**Symptom:** a lane (or the whole node) has **no scoring at all** after a power
blip, UPS event, or reboot — not "wrong score," but *gone*. Health check shows the
node disconnected.

**Likely cause:** the systemd `lane-node` service is **loaded/active but not
`enabled`**, so it does **not** start on boot. This is a real trap that was hit on
the bench rig: the service ran fine for days only because the Pi had not rebooted.

**Fix:**
```bash
sudo systemctl enable lane-node      # make it start on boot (the missing step)
sudo systemctl restart lane-node     # start it now
systemctl is-enabled lane-node       # must print: enabled
journalctl -u lane-node -f           # confirm it comes up
```

> **Provisioning rule:** `systemctl enable lane-node` **must** be part of every
> node's provisioning runbook. The symptom of a missing enable is exactly "lane
> goes dark after any power event." (`docs/phase8_trackA_golive_runbook.md`
> failure cheat-sheet; project provisioning note.)

> **(VERIFY: the Track-B controller daemon's own service unit.)** The
> `lane-node` service above is the **scoring** node (`lane_node/lane_node.py`). The
> Track-B **controller** daemon (`lane_node/controller_daemon.py`) is a *separate*
> tight synchronous control loop and is **not yet unified** with the scoring/server
> path (the file's `TODO(server)`); its production service unit / `systemctl enable`
> step is a cutover item not fixed in the files read here. The same enable-on-boot
> rule will apply.

---

### 22.4 Relays will not energize / the rail dropped (Track B, bench/cutover)

> **Context:** This applies to the **Track-B controller board** during bench
> bring-up or cutover — Track B is **not yet cleared for live machines**. Do this
> on a **locked-out / off** machine (§22.0).

A motion relay (S/T/SP/BE/M/M2) energizes **only if both** of two independent gates
are satisfied (§9, §10.5):

- **(a)** the Pi sets that relay's bit on **MCP23017 OUT-A** (chip `0x22`) — turns
  on the per-relay NPN driver that grounds the coil low side; **and**
- **(b)** the **relay-enable rail** (`RELAY_ENABLE_RAIL`) is live — supplying +5 V
  to the coil high side through the pass-FET **Q14 (AO3401A)**.

Software alone can never fire a coil. If relays won't energize, first determine
whether the **rail** is dead or the **command** is missing.

#### 22.4.1 First measurement: is the rail live?

Probe **`RELAY_ENABLE_RAIL` at TP16** (the rail test pad; §10.8):

- **≈ +5 V** → the rail is up; the problem is the command path (jump to §22.4.3).
- **≈ 0 V** (or pulled toward the coil-low side through the coils) → the rail is
  dead; an implemented gate/source position is open (continue below).

#### 22.4.2 Board permissions and the separate Candidate-C OEM guard

The PCB contract names six conditions, but lane 21/22's Candidate-C field
implementation does **not** put TB/SC on J14. Pins 1–2 carry the controlled,
labeled jumper; pins 3–4 are reserved for an external control-power / optional
pit-interlock dry-contact interface but are currently physically OPEN/unlanded. The OEM parallel closed-when-safe TB/SC
contacts remain separately in the S/T coil ladder. Read the board permissions in
this order, then run the separate G3 coil proof:

| # | Condition | How to read it | "Permit" state | Common cause of a false |
|---|---|---|---|---|
| 2 | **Arm OK** | `ARM_PERMIT` at **J1 (J_PI) pin 8** | HIGH | Pi hasn't armed: FSM not in a runnable state, or it latched into MANUAL_INTERVENTION/FAULT (§22.5). Default false via R108 100 k base pulldown. |
| 1 | **Watchdog OK** | `WDOG_KICK` at **J1 pin 7** should show periodic pulses; `NE555_OUT` (U36 pin 3) toggles; `WDOG_OK_PULLDOWN` (Q13 drain) pulled to GND while OK | kicks present | Pi process hung/stopped → no kicks → NE555 times out → Q13 off. Or the kick GPIO isn't wired/asserted. |
| 3 | **RP2040 OK** | `RP2040_OK` = **GP2**, at **J1 pin 13** | HIGH | RP2040 unpowered / in reset / BOOTSEL / firmware crash / cam-stop or motion-timeout fault. GP2 is Hi-Z when unpowered → R110 100 k holds Q16 off. |
| 4 | **Enabled cam-stop OK** | *(not a separate transistor)* — folds into condition 3 | (see #3) | An enabled enforcement fault or the active motion timeout drives **GP2 LOW**. Stock v1.2.3 measured-cam flags are OFF. |
| 5 | **J_SAFE1-2 board source position** | controlled Candidate-C jumper on **J14 pins 1↔2**; `SAFE_TBSC_RETURN` | keyed/labeled jumper present | Missing/loose controlled jumper. This is **not** a TB/SC field sensor and opening it proves only PCB/source continuity. |
| 6 | **Reserved external control-power / optional pit-interlock source position** | **J14 pins 3↔4**; `SAFE_STOP_RETURN` (Q14 source) | current field state is OPEN/dead; future permit requires a reviewed isolated dry-contact interface | The current OPEN/unlanded harness is expected and deliberately prevents arm. Never install a machine-side jumper as a “fix,” and never route machine voltage or mains onto Rev-D. |

**Structural facts** (so you know what to expect on a meter):

- **J_SAFE1-2 and J_SAFE3-4 are in series with the FET source.** +5 V enters
  J14.1, traverses the Candidate-C jumper to J14.2, crosses the on-board
  J14.2/J14.3 net, then stops at the current open/unlanded 3–4 position.
  A future approved interface can return on J14.4 to the pass-FET source.
  Opening either completed connector position proves board/source continuity
  only; it does not prove the OEM TB/SC guard or Stop-to-breaker path.
- **Conditions 1, 2, 3(=4) are a series transistor stack on the FET *gate***
  (`RAIL_GATE`, held up to the source by R106 100 k = off by default):
  **Q15 (ARM) · Q16 (RP2040_OK) · Q13 (watchdog) must all conduct** to pull the
  gate low and turn the P-FET on. Any one off → gate stays up → rail dead.

> **Candidate-C diagnostic boundary:** if J_SAFE1-2 is open, the rail should be
> dead; restore only the documented keyed/labeled jumper. Never search C2A-U or a
> ~21 Ω cold-continuity path for a replacement field loop. The authoritative
> collision test is live/per-lane under the runbook's guarded procedure: command S,
> then T, force both levers BACK/open, and require each machine coil to remain dead.
> A failure means the board output bypassed the OEM ladder: abort and roll back.
>
> **Stop / pit-entry diagnostic boundary:** current J_SAFE3-4 OPEN is not a fault
> to bypass; it is the intended no-arm hold. The leading interface is an externally
> mounted, correctly rated energize-to-prove control-power relay whose isolated
> N.O. dry contact alone reaches J14, optionally in series with an approved new
> pit-entry-interlock contact. After it exists, a 3–4 continuity/drop test proves
> only the board source path. On lanes 21/22, actuate Stop and require it to drop
> OEM master/control power and TP16; record C.I.S. as **N/A — device absent**.
> Inspect/ask the mechanic about any other automatic pit-entry interlock and
> separately demand-test it if found or installed. If none exists, close the
> new-interlock-versus-explicit-safety-decision gate before motion. A J14-only pit
> switch is board permission gating, not an upstream final disconnect. A welded or
> stuck-closed sensing-relay contact can look healthy, so the acceptance and
> periodic proof must force control-power loss and verify both the contact opens
> and TP16 drops. Only the monitor's isolated dry contact reaches J14; sensed
> machine voltage and mains remain outside Rev-D.

#### 22.4.3 Rail is live but a specific relay won't fire

If TP16 is ≈ +5 V but one output doesn't actuate, the **command** path or that
**channel** is the problem:

| Likely cause | Check / fix |
|---|---|
| **Pi isn't setting the OUT-A bit** | The FSM drives relays via `MachineIO._set_out()` over I²C to MCP23017 `0x22`. Confirm the FSM is actually in a state that commands that motor (§22.5 / §3). |
| **Wrong bit ↔ relay mapping** | `controller_io.OUT_A_MAP` is the source of truth and is regression-checked against the netlist generator. S=(0,0), T=(0,1), SP=(0,2), BE=(0,3), M=(0,4), **M2=(0,5)**, **M1=(0,6)**; lamps first_ball=(0,7), second_ball=(1,0), strike=(1,1), foul=(1,2). (M2 is bit 5, **before** M1 bit 6 — per the generator. BS/OS, M1/M2, strike/foul were once swapped and have been corrected to match the netlist — see §12.) |
| **M1 (ball return) won't fire — by design** | **K7/M1 is DNP** (do-not-populate): not bench-confirmed on these chassis and the FSM doesn't drive it. The coil/driver/flyback footprints exist on the rail but are not assembled. Do not expect M1 to work until it is verified at-machine and populated (spec §3.2, §11 item 6). |
| **I²C bus not enumerating** | All three board MCP23017s must come up: **IN-A `0x20`, IN-B `0x21`, OUT-A `0x22`** on the board's own bus. If `MachineIO` can't open the bus or a chip NAKs, no outputs (or no slow inputs) work. Confirm with `i2cdetect` on the board's bus and check the 3.3 V rail + the two 4.7 k I²C pull-ups. |
| **Coil driver / relay fault** | Probe the per-relay NPN (Q1–Q6 for S/T/SP/BE/M/M2; Q7 is M1 DNP) and the coil. The flyback diodes are D1,D3,D5,D7,D9,D11 (1N4148WS) across the coils. |

#### 22.4.4 A relay coil drops but the machine circuit stays made (welded contact)

**The rail de-energizes coils; it cannot open a welded-closed contact** (§10.6,
spec §4.5). If a contact welds, dropping the rail removes coil drive but the welded
contact — and the machine control circuit it feeds — stays made.

- The **final physical stop is the rear-panel master breaker** (installed Stop chain
  on lanes 21/22),
  not the rail. Cut it.
- This is why **relay contact rating + arc suppression are safety-relevant.** Each
  motion output has **DNP** footprints for an RC snubber (`Rsnub_*` 100 R +
  `Csnub_*` 10 nF X2) and a **MOV** across the contact — populate per output after
  measuring the actual inductive AC control load (spec §2.3, §3.2, §11 item 1).

If a CT/Hall sensor reports motor current while the controller command is OFF,
classify it as **`uncommanded_motor_current`** and report the suspected cause as
**external-feed-or-welded**. The current measurement cannot distinguish a welded
contact from another external feed or bypass. Escalate and prove the circuit/contact
state before assigning a `welded_contact` diagnosis.

---

### 22.5 Motion-timeout / cam-stop faults (Track B)

**Symptom:** a motor starts, runs longer than expected, then **everything stops and
the rail drops**; the FSM/firmware reports a fault.

There are **two independent timeout backstops**, both at the same 8-second budget,
which together fail the motion safe:

1. **FSM software backstop — `MAX_MOTION_S = 8.0 s`** (`cycle_control_8270.py`).
   In `poll()`, if any motion state (`SWEEP_TO_GUARD`, `TABLE_DETECT`,
   `RUNTHROUGH`, `SPOTTING`, `TABLE_FINISH`) is held longer than `MAX_MOTION_S`,
   the FSM logs `FAULT — <state> > 8.0s; motors OFF`, drives all motors off, and
   enters `State.FAULT`.
2. **RP2040 firmware backstop — `MAX_MOTION_MS = 8000` ("cam timeout", spec §4.2;
   `firmware/rp2040/config.h`).** If the Pi marks a *guarded* motor `RUN` over UART
   and never `STOP`s it within 8 s, the firmware **latches a fault and drops
   `RP2040_OK` (GP2) LOW** → rail dead. It emits `{"ev":"flt","code":"motion_timeout","m":"S"}`.
   (BE and M are **not** max-run-guarded — BE is continuous, M is master/power.)

| Likely cause | Fix |
|---|---|
| **A motor genuinely never reached its cam-stop angle** (mechanical bind, slipping cam, motor not turning, or a cam switch not tripping) | This is the backstop doing its job. Lock out and inspect the mechanism / the relevant cam switch (§3, §4). The cam that should have stopped the motion: SA (sweep 270 run-through / 360 zero), SB (sweep 66 guard), TA1 (table 355 zero / 185 delay reset), TA2 (table 260). |
| **`MAX_MOTION_S` / `MAX_MOTION_MS` set too tight** for the real machine | The field rule is "set = measured + margin" (`cycle_control_8270.py` comment). If a *healthy* motion legitimately takes longer than 8 s on this machine, the budget needs raising — but **measure first**; do not loosen a safety backstop without data. |
| **Cam edge polarity / cam-stop overrun** | v1.2.3 contains the enforcement code, but all measured-cam flags ship **OFF**. Capture each independently landed motion-cam edge→angle polarity, bind only confirmed values into a **new controlled release**, and pass its bench gate. Stock v1.2.3 provides health + max-run only. |

**To recover from a latched fault** (firmware side):
- The Pi sends **`CLEAR`** to the RP2040 **only from a known-safe zero/ready
  state**; the firmware then re-permits (GP2 back HIGH). In the daemon, `CLEAR` is
  sent together with the operator's **First-Ball-Zero (PBZ)** re-arm
  (`controller_daemon._slow_actions`: PBZ → `fsm.first_ball_zero()` **and**
  `link.clear()`).
- The FSM's own `FAULT`/`MANUAL_INTERVENTION` states require a **deliberate
  First-Ball-Zero (PBZ)** to return to `READY` — there is **no auto-rearm**
  (`controller_daemon.py` health-loss safety trip; self-test "recovery does NOT
  auto-rearm"). This is intentional: a stale relay latch must never silently
  resume motion.

> **Power-restore behavior is the same idea:** the FSM comes up in
> **MANUAL_INTERVENTION** and drives nothing until the operator presses PBZ
> (`power_restore()`; the MP "Power-Down" rule, spec §5). A board that just powered
> on and "won't move" is behaving correctly.

---

### 22.6 RP2040 link dead / cam & ball events missing (UART)

**Symptom:** cam/ball events stop reaching the FSM; the daemon logs the RP2040 link
**LOST** and trips safe; `RP2040_OK`/the rail drops.

The RP2040 owns the **8 fast inputs** (6 cams + 2 DIELL ball beams) and pushes edge
events to the Pi over **UART0, 115200 8N1, newline-delimited JSON** (`GP0`=TX→Pi RX,
`GP1`=RX←Pi TX; firmware README, `rp2040_link.py`). The Pi tracks RP2040 health and
trips the FSM safe if it goes unhealthy.

**How the Pi judges health** (`rp2040_link.health_ok()`): healthy **only if** the
RP2040 is heartbeating (a `boot`/`hb`/`rp_ok`/`flt`/`ack` line within the
**`hb_timeout` = 1.0 s** window) **AND** reports `rp_ok` true **AND** has no latched
fault. A bare `flt` event marks it unhealthy immediately, even without a paired
`rp_ok:0` (lossy-UART robustness). The firmware heartbeats at **`HB_INTERVAL_MS` =
250 ms** (~4 Hz).

**What the daemon does on health loss** (`controller_daemon.BoardController.tick()`):
forces motion outputs **off** (clears the relay latches), latches the FSM into
**MANUAL_INTERVENTION** (recovery requires a deliberate PBZ), drops **ARM**, and
keeps kicking the NE555 (the *Pi* is still alive). Note that `RP2040_OK` has
**already** dropped the rail in hardware regardless — the daemon's action is the
software belt-and-suspenders so the FSM/desk see it.

| Likely cause | Fix |
|---|---|
| **UART not wired / wrong port** | Confirm the Pi's serial device for this board (`controller_daemon.DEFAULT_BOARDS` `uart_port`, e.g. `/dev/ttyAMA0` — **all `# CONFIRM` placeholders set at bench/cutover**). TX/RX must be **crossed**: Pi TX → Pico `GP1`/RX, Pico `GP0`/TX → Pi RX. Baud **115200 8N1**. |
| **RP2040 unpowered / not flashed / crashed** | Confirm a `boot` line then ~4 Hz `hb` with `ok:1`. If the firmware hung, its **internal hardware watchdog** (`WDT_TIMEOUT_MS` = 250 ms) resets the chip — you'll see a `boot` with `wdt_reset:1`. After reset, GP2 is held LOW for `BOOT_SETTLE_MS` = 200 ms, then HIGH only if healthy. |
| **Stale heartbeat (link "alive" but quiet)** | If no line arrives for > 1.0 s, `is_alive()`/`health_ok()` go false → daemon trips safe. Check the cable, the Pico power, and that the reader thread is running (`RP2040Link.start()`). |
| **Latched firmware fault** | `health_ok()` stays false until an `hb` with `flt:""` arrives — i.e. after a `CLEAR` from a safe state (§22.5). |
| **Cam events arrive but the FSM ignores them** | The FSM only acts on a configured, measured trip edge and in the matching state. SC/TB are not FSM motion-cam calls; their code path is only the default-off/unvalidated software echo. Lane 21/22 has no independent TB lead and SC/U is unlanded, so do not expect or credit that echo. |

**To verify the fast inputs at the bench** (firmware README §"Bench bring-up"
step 2): hand-actuate each cam / break each DIELL beam and confirm the matching
`{"ev":"cam","id":...}` / `{"ev":"ball","src":...}` line (correct `id`). All fast
inputs are **active-low** at the Pico (machine contact closed ⇒ GPIO LOW; on-board
external `Rpu_*` holds idle at 3.3 V: Rev-B 10 kΩ, current Rev-D **47 kΩ**).
On Rev-D, verify GP6–GP13 PUE/PDE are off; an internal pull can hide an open
external `Rpu_*` and invalidates the qualified input margin. The GP↔signal map
(`config.h` / §12):

| GPIO | Pico pin | Signal |
|---|---|---|
| GP6 | 9 | SA (sweep cam) |
| GP7 | 10 | SB (sweep cam) |
| GP8 | 11 | SC (sweep interlock cam) |
| GP9 | 12 | TA1 (table cam) |
| GP10 | 14 | TA2 (table cam) |
| GP11 | 15 | TB (table interlock cam) |
| GP12 | 16 | DIELL-L (ball) |
| GP13 | 17 | DIELL-R (ball) |
| GP2 | 4 | RP2040_OK (rail permission) |
| GP0 / GP1 | 1 / 2 | UART0 TX / RX to Pi |

> ⚠️ **Do not use the GPIO column in `docs/phase8_channel_allocation.md` §2** — it
> assigns the fast inputs to GP0–GP7 and is **stale**. The as-built board uses
> **GP6–GP13**; `firmware/rp2040/config.h` and the netlist generator are correct
> (see §12).

**Re-flashing the RP2040 firmware** (firmware README §"Flash"):
- **USB BOOTSEL (preferred):** hold BOOTSEL on the Pico while connecting USB → it
  mounts as `RPI-RP2` → drag-drop `wsl_phase8b_rp2040.uf2`.
- **SWD (if USB inaccessible once soldered):** `picotool load -x build/wsl_phase8b_rp2040.uf2`,
  or OpenOCD via the board's SWD test points.
- Rebuild on the Westside laptop with `pwsh -File build.ps1` (auto-discovers the
  bootstrapped toolchain → `build/wsl_phase8b_rp2040.uf2`, ~40 KB).

---

### 22.7 The watchdog & health behavior (what "healthy" looks like)

Two **independent** watchdogs guard two different things — **do not confuse them**
(§10.2):

| Watchdog | Watches | Timeout | What it does on timeout |
|---|---|---|---|
| **NE555 monostable** (U36, on the board) | the **Raspberry Pi** | (monostable RC; bench-measured) | Pi stops kicking → NE555 reverts → Q13 off → rail AND opens → **all relay coils drop** |
| **RP2040 internal HW watchdog** | the **Pico firmware** | `WDT_TIMEOUT_MS` = 250 ms | firmware loop hangs → chip resets → GP2 → Hi-Z → R110 holds Q16 off → **rail drops**; auto-recovers on reboot (`boot` with `wdt_reset:1`) |

The Pi **kicks the NE555 only from `fsm.poll()`** inside the control loop
(`controller_io.MachineIO.watchdog_kick()`, called every `poll()`). This coupling is
**intentional**: if the Track-B control loop stalls, kicks stop and the rail drops.
(Contrast Track A, where scoring must **never** be able to stop the machine.)

A healthy RP2040 at the bench:
- a `boot` line on power-up, then `{"ev":"hb",...,"ok":1}` at ~4 Hz after ~200 ms;
- `GP2` reads **HIGH** on a meter/test-pad once healthy;
- the daemon's `link.health_ok()` returns true.

> **(VERIFY: NE555 monostable timeout period and the Pi kick GPIO number.)** The
> watchdog RC is R100 = 100 k + C11 = 100 µF, but the kick is wired into both the
> timing and trigger nodes (retrigger topology) and the design doc states the drop
> behavior **qualitatively** without a number (spec §4.3). The effective drop time
> is a **bench measurement** (§10.8 / spec §12.9 "watchdog drop") — **do not assume
> ~11 s.** Likewise the Pi-side **kick GPIO number** (and the per-board **ARM** GPIO)
> are `# CONFIRM` placeholders in `controller_daemon.DEFAULT_BOARDS` set at bench/
> cutover — the *board* side is fixed at J1 pin 7 (`WDOG_KICK`) and J1 pin 8
> (`ARM_PERMIT`).

---

### 22.8 Periodic maintenance

Most of this system is solid-state with no wear parts; the maintenance load is
light. Recommended checks:

**Track A — scoring (per-pair, ongoing):**
- **Accuracy spot-check.** Keep a casual detected-vs-actual tally during play; a
  drift toward a particular pin/spot is a calibration nudge (§22.2.3), not a
  failure.
- **Empty-reference refresh** if the camera is moved/reseated, the dongle changes,
  or lighting changes materially: recapture `empty_ref.png` (§22.2.1). The detector
  drift-corrects exposure, so routine lighting swings should not need it.
- **Confirm `systemctl is-enabled lane-node` = enabled** after any maintenance that
  touched the Pi or its OS (§22.3) — the most common way a lane silently goes dark.
- **Camera tap ground integrity** — a marginal RCA-shell→Blue ground shows up as
  intermittent black frames (§22.2.2).

**Track B — controller (per-board; once cleared for live):**
- **Re-run the bench safety drops periodically** on a locked-out machine: watchdog
  drop, ARM drop, J_SAFE1-2 source-position drop, approved J_SAFE3-4
  source-position drop, and motion-timeout drop (§10.8). Opening either J_SAFE
  position proves only board continuity. Under the current
  runbook's guarded live procedure, also re-prove Candidate C per lane: command S
  and T separately; both levers BACK/open must leave each machine coil dead.
- **Demand Stop** under the guarded procedure and verify it drops OEM
  master/control power and TP16. Record C.I.S. as **N/A — device absent** on
  lanes 21/22; never silently waive the missing test. Separately re-prove any
  identified or newly installed pit-entry interlock, and force a control-power
  loss to prove the energize-to-prove relay contact is not stuck closed. Do not
  infer any result from healthy-state continuity; a bypass or weld is latent
  until demanded.
- **Mains-integrity check:** at commissioning and periodically, have a qualified
  electrician use an appropriately listed external tester to record
  protective-earth continuity/bonding and correct hot/neutral polarity. Never
  route mains to Rev-D or J14.
- **Inspect motion-relay contacts + suppression** on inductive outputs (S/T/SP/BE/M/M2)
  for arcing/pitting; verify the populated snubber/MOV per output (§22.4.4).
- **Verify test-point readings** against §10.8 (TP16 rail, `RAIL_GATE`, `NE555_TRIG`/
  `NE555_OUT`, `SAFE_STOP_RETURN`, `RP2040_OK`, `ARM_PERMIT`, `WDOG_KICK`).
- **Confirm the per-cam trip edges** are still as captured before any newly
  controlled release enables cam-stop overrun; stock v1.2.3 leaves them OFF.

**Software hygiene:**
- On the Pi: `git pull` only deliberately (it brings `camera.py` / `lane_node.py` /
  calibrated `pin_detect.py`); **`empty_ref.png` is per-Pi and gitignored** — never
  expect a pull to provide it.
- Watch `journalctl -u lane-node -f` after any change; the runbook log strings
  (§22.2) are your go/no-go.

---

### 22.9 Spares to keep on hand

The strategic goal of Phase 8 is **zero EOL hardware** — every active part is a
commodity, in-stock device chosen so the center is not hostage to a defunct vendor.
That said, keep a small spares kit so a failure is a swap, not a fab order.

#### 22.9.1 Whole-unit / module spares (highest priority)

| Spare | Why | Notes |
|---|---|---|
| **A complete spare controller board (PCBA)** | Fastest recovery is board swap, not component-level repair, on a 250 × 225 mm board | The board is a single, identical, per-lane design — one spare fits any 82-70 lane. Fab/assemble a couple of extras with each batch. |
| **Raspberry Pi (per-pair host)** | Runs scoring + control; commodity, cheap | Keep the OS image + the node config so a swap is reflash-and-go. **Remember `systemctl enable lane-node`** on any fresh Pi (§22.3). |
| **Raspberry Pi Pico (RP2040 stamp module), ref A1 / RP_PICO** | The fast/safety co-processor; socketed-module choice was deliberate to make it swappable | **DigiKey 2648-SC0915CT-ND / Raspberry Pi SC0915.** Use the **plain Pico (castellated, no headers)** — **NOT** the Pico H/WH with header pins. Flash `wsl_phase8b_rp2040.uf2` after fitting (§22.6). |
| **VIXLW USB capture dongle** | The only thing between the camera and the Pi for Track A | UVC-class; enumerates as "USB Video." |

#### 22.9.2 Board-level component spares (for hand repair)

Confirmed, fab-locked parts from the assembly BOM
(`kicad/fab_revB_routed_manual/assembly/wsl-phase8b-revB-jlc-standard-pcba-bom.csv`).
**Use these exact parts** — the critical-substitution notes are load-bearing:

| Part | Role | Designators | LCSC | Critical note |
|---|---|---|---|---|
| **Omron G5LE-14, 5 VDC coil**, SPDT relay (THT) | Motion-output relays | K1–K6 (K7/M1 = **DNP**) | **C116963** | **5 VDC coil — DO NOT substitute a 9 V / 12 V / 24 V coil.** Carries no motor current; switches dry contacts only. |
| **MCP23017-E/SO** I²C 16-bit I/O expander (SOIC-28W) | Slow inputs + relay/lamp outputs | U1, U2, U3 | **C47023** | **I²C part — NOT the SPI `MCP23S17`.** Runs at **3.3 V** for Pi-safe I²C. (IN-A `0x20`, IN-B `0x21`, OUT-A `0x22`.) |
| **PC817B** optocoupler (DIP-4) | Isolates every machine input | U4–U35 (32 pcs) | **C5692981** | Logic side at 3.3 V, **active-low** at the MCU. Keep CTR bin consistent with the Rev-B field resistors. |
| **NE555DR** (TI), **bipolar** 555 (SOIC-8) | Hardware watchdog monostable | U36 | **C7593** | **Bipolar NE555 — avoid CMOS/TLC555**; the timing/threshold behavior would change. |
| **AO3401A** P-ch MOSFET (SOT-23) | Relay-enable-**rail pass-FET** | Q14 | C347476 | High-side rail switch. Don't confuse with the N-ch parts below. |
| **AO3400A** N-ch MOSFET (SOT-23) | Watchdog kick (Q12) + watchdog-OK (Q13) | Q12, Q13 | C20917 | **Q12/Q13/Q14 are visually similar SOT-23 parts — do not swap N-ch and P-ch during hand placement.** |
| **MMBT3904** NPN BJT (SOT-23) | Relay-coil drivers (Q1–Q6) + safety-chain AND transistors (Q15, Q16) | Q1–Q6, Q15, Q16 | C909754 | One grouped BOM line for all 8; confirm by role/position. |
| **2N7002** N-ch MOSFET (SOT-23) | Low-side status-LED drivers | Q8–Q11 | C916396 | The 4 mask-LED channels. |
| **SS14** Schottky (SMA) | Reverse-polarity / input protection on the 5 V input | D17 | C2480 | |
| **1N4148WS** (SOD-323) | Relay-coil flybacks + watchdog steering diodes | D1,D3,D5,D7,D9,D11,D15,D16 | C118873 | |
| **TRACO TMA-0505S** isolated 5 V→5 V DC/DC (THT) | Isolated **field-wetting** supply (keeps FIELD_GND off logic ground) | U37 (ISO_WET) | *(see note)* | DigiKey 1951-1003-ND. **Do not substitute without a pinout + isolation review.** Not in the JLC SMT BOM — placed/hand-fitted. |
| 0805 R/C passives (4.7 k, 2.2 k, 10 k, 1 k, 100 k, 330 R; 100 nF, 10 nF, 10 µF; 100 µF/16 V electrolytic C11) | Pull-ups/-downs, gate Rs, decoupling, watchdog RC | many | (grouped) | Confirm passives **by value**, not by assuming a unique BOM line per RefDes. |

> **(VERIFY: LCSC/MFR number for the TMA-0505S.)** The isolated wetting supply is
> **TMA-0505S** in the as-built netlist (`block_supplies()`, ref ISO_WET → board ref
> **U37**) and the hand-solder BOM (TRACO `TMA 0505S`, "Locked exact part"). An
> earlier draft (`docs/phase8b_pcb_revB_BOM_power.md` §3.2) *recommended* a
> `B0505S-1W` — **the netlist (source of truth) wins: use the TRACO TMA-0505S.** It
> is not in the JLC SMT upload BOM, so it has no LCSC line in that file; order from
> DigiKey/TME/Mouser and verify the pinout before fitting.

#### 22.9.3 Connector / mating-part spares

Field-input and machine-output connectors are **Phoenix Contact MCV/MKDS** series
(from the hand-solder/off-board BOM). Keep the **mating plugs** as spares — the PCB
headers are soldered, the plugs are field-wiring and get reworked:

| Board connector | Part (header on PCB) | Mating plug to stock |
|---|---|---|
| J3 (J_FAST_IN, 10-pos, 3.5 mm) | Phoenix MCV 1,5/10-G-3,5 (1843680) | MC 1,5/10-ST-3,5 |
| J4 (J_SLOW_IN_A, 14-pos) | MCV 1,5/14-G-3,5 (1843729) | MC 1,5/14-ST-3,5 |
| J5 (J_SLOW_IN_B, 12-pos) | MCV 1,5/12-G-3,5 (1843703) | MC 1,5/12-ST-3,5 |
| J13 (J_LAMP_LED, 6-pos) | MCV 1,5/6-G-3,5 (1843648) | MC 1,5/6-ST-3,5 |
| J14 (J_SAFETY, 4-pos) | MCV 1,5/4-G-3,5 (1843622) | MC 1,5/4-ST-3,5 |
| J2 (J_PWR 5 V, 3-pos, 5.08 mm) | Phoenix MKDS 1,5/3-5,08 (1715734) | fixed screw terminal (no off-board plug) |
| J6–J11 (J_MOTION_*, 2-pos, 5.08 mm) | Phoenix MKDS 1,5/2-5,08 (1715721) | fixed screw terminal (no off-board plug) |
| J1 (J_PI, 2×10 IDC) | 20-pos 2×10 2.54 mm header | ribbon/IDC socket to the Pi |

#### 22.9.4 EOL-risk machine parts (the parts Phase 8 exists to escape)

These are **legacy** parts on the machine/scoring side that are end-of-life with no
viable supply chain. Where the original is being **retired** by Phase 8, the "spare"
is the Phase 8 replacement, not the EOL part. Stock the few that are still in the
loop:

| EOL part | Status under Phase 8 | Spares stance |
|---|---|---|
| **QubicaAMF T-Camera** (one per pair) | **Reused** by Track A (its composite video is tapped) | The camera is still in the live path — keep any spare T-Cameras you have; they are EOL from QubicaAMF. |
| **QubicaAMF VDB** (per-lane scoring computer), **ETHost** gateway, **T-VISION** board | **Retired** — replaced by the Pi + camera scoring | Don't invest in spares; the Pi-per-pair build *is* the replacement. Keep enough only to cover lanes not yet cut over. |
| **Omega-Tek "Omniboard"** retrofit controller (lanes 21/22) + Expander/ZOT | **Being replaced** by the rev-B controller (Track B) | **Vendor appears defunct** → highest continuity risk and a primary motivation for Phase 8. Keep whatever spares exist for lanes not yet cut over; the long-term answer is the Phase 8 board. |
| **Active "Ultra 98 Plus" MP controller** (lanes 11/12) | Being replaced by Track B over time | Mixed fleet; keep until that pair is cut over. |
| **AMF 82-70 machine mechanism, motors, cams, grippers, mask** | **KEPT** — unchanged on every lane | Standard pinsetter wear parts (cam microswitches, gripper switches GS1–GS10, motor contactors, drive components) per normal AMF 82-70 service stock. The Phase 8 board reads/commands these; it does not replace them. `(VERIFY: specific AMF 82-70 mechanical part numbers — outside the named live files; use the AMF 82-70 Service & Parts manual.)` |

---

### 22.10 When to stop and escalate

- **Any time the safe fallback is available, take it.** Flip Track A to `manual`
  (§22.2.5) — the lane runs and the desk scores. There is no machine risk.
- **Do not run Track B against a live machine** until the full hardware safety
  chain is bench-proven per §10.8 / spec §12.9 and the cutover runbook
  (`docs/phase8_trackB_controller_cutover_runbook.md`). The controlled v1.2.3
  bundle is **NOT flashed or cutover-ready**; its measured-cam enforcement flags
  are OFF, and first-article/bench gates remain open.
- **A dead rail during diagnosis is the safe state**, not necessarily a fault
  (§22.0 item 6). Confirm which implemented gate/source position is open (§22.4.2) before
  assuming a board failure.
- **If a relay contact may have welded**, the rail will not save you — cut the
  master breaker (§22.4.4, §10.6).

> **Cross-references:** machine theory and the cycle/cam timing in **§3**; the I/O
> inventory in **§4**; the board domains/isolation in **§5**; power rails in **§6**;
> RP2040/MCP/I²C logic in **§7**; opto front-ends in **§8**; relay outputs in **§9**;
> the watchdog + relay-enable rail (and its test points + bench-drop procedure) in
> **§10**; connector pinouts in **§11**; the GPIO/MCP bit maps in **§12**; and the
> machine-side C1/C2A harness in **§14**.

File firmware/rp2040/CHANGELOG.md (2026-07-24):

# WSL Phase 8b — RP2040 lane-controller firmware — CHANGELOG

All entries newest-first. "Flashed" status is tracked per entry — a written version is
NOT a deployed version. Line-format changes are ADDITIVE-ONLY by policy: the Pi-side
parser (`lane_node/rp2040_link.py`) ignores unknown JSON keys and unknown `ev` kinds.

## v1.2.3 — 2026-07-23 — Codex round-3 R3-6 + firmware half of R3-5 (CLEAR pad-revalidation, FI-1 dead-man, boot nonce). NOT FLASHED.

Scope = the round-3 firmware slice of the rev-D remediation (Codex re-audit regrade,
adversarial reproductions). All three line-format additions are ADDITIVE (`bn` key);
`rp2040_link.py` must gain the boot-nonce cache-invalidation consumer (Pi-side task —
see followups; the field is defined here and repeated on boot/id/hb).

- **R3-6 — CLEAR synchronously revalidates the input-only pads.** Pre-fix, `CLEAR`
  dropped the fault latch unconditionally and `supervise()` could reassert RP_OK for up
  to one heartbeat tick (250 ms) while a driveable "input" pad persisted — the invariant
  only re-ran at the next `tap_hb_tick()`. Now the `CLEAR` handler runs the FAIL-SAFE
  half first and unconditionally (`motors_all_stop()` + `camstop_all_disarm()`), then
  re-runs the full `tap_assert_input_only()` (SIO dir + funcsel + OEOVER field + live
  OETOPAD pad bit on taps GP16-19, ADC GP26, fast inputs GP6-13, REV_ID GP20-21) BEFORE
  clearing the latch. A persistent violation makes the recovery a strict no-op: the fault
  stays latched, RP_OK stays low, and the Pi gets a `nak` line naming the fault code. The
  fail-safe half is deliberately NOT gated (a refusal must never be less safe than an
  accept). Host test `test_v12.c` section U: clean-pad CLEAR still clears (regression
  guard); violated-pad CLEAR → nak + fault latched + RP_OK stays low; restored-pad CLEAR
  succeeds.

- **R3-6 — FI-1 dead-man hardening (bench build only).** The FI-1 fault-injection image
  gained four INDEPENDENT fail-safe auto-release paths, all supervised by `fi1_service()`
  (called every main-loop pass, after `poll_uart()` so it sees the freshest RX/KA stamps,
  before `supervise()` so a re-latch drops RP_OK the same pass): **arm timeout** (`FI1 ARM`
  with no `DRIVE` for 10 s auto-disarms), **drive timeout** (any injection older than 60 s
  releases), **UART loss** (no uart0 RX byte for 2 s while driving → the bench host is gone
  → release), and a **continuous dead-man** (`FI1 KA` token required every 3 s while
  driving, else release — catches a live link whose operator script stopped). Every
  auto-release restores the locked input-only contract and re-verifies it (`autorel` event
  with `why` + `ok`). `fi1_last_rx_ms` is now stamped on EVERY received byte (not per parsed
  line) so an overrun/garbage stream still counts as a live link. Host test `test_fi1.c`
  section E proves each release path fires, restores the pin, and (E5) that the 1 Hz bench
  KA cadence holds an injection across 10 s with no false release. `test_fi1`: 28 → **44**.

- **R3-5 (firmware half) — per-boot nonce.** The tap-ring epoch resets to 1 on power loss,
  so two cold boots are epoch-indistinguishable and a Pi that missed the boot line could
  keep trusting stale cached identity/capability state. A fresh 32-bit nonce (32 ROSC
  `randombit` reads decorrelated by 1 µs gaps, XOR the boot-time µs clock; 0 reserved =
  legacy/unknown) is sampled every boot and carried in the `bn` field on the boot line, the
  id line AND every heartbeat — a `bn` change on ANY beat is an unambiguous "rebooted since
  your cache" signal even when the boot line itself was lost. Identity is re-emitted after
  every boot and on `ID`. The Pi-side consumer (drop ALL cached identity/capability state on
  a `bn` change or boot line) is a `rp2040_link.py` task coordinated with the lane agent —
  see followups. Host test `test_v12.c` section T: nonce non-zero, differs across boots,
  consistent across id+hb of one boot, and the 0-reservation guard holds over 64 boots.

- **fmtbuf SIZE BUDGET re-counted** for the added `bn` field: worst boot ~199 B, hb ~200 B,
  id ~206 B in the 256 B buffer; TXR_HEADROOM (320) still ≥ the worst flt+rp_ok+hb burst
  (~300 B). No safety path weakened — every new path is a fail-safe RELEASE or a REFUSAL.

- **Deterministic release provenance.** `id.build` no longer uses repository-wide
  `git describe --dirty`, where an unrelated document or KiCad edit changed the firmware
  identity without changing the image. It is now a variant-prefixed digest over an explicit
  firmware source/recipe allowlist, image-affecting build options, exact clean Pico SDK
  commit, and C compiler ID/version. A different SDK/compiler therefore cannot announce
  the allowlisted runtime identity. `id.cfg` is the exact 16-character prefix of the full
  `config.h` SHA-256. `release.ps1` builds both
  Release/DEBUG_USB-off images, refuses ambient compiler flags and a dirty Pico SDK, then
  writes and verifies `release/firmware_manifest.json`: both UF2 SHA-256 values, their
  embedded `id.build`/`id.cfg`/`id.fi1`, full source/config digests, CMake caches, compiler
  versions, and clean SDK commit. The deployment allowlist contains only the release image;
  FI-1 remains bench-only. Host provenance tests pin that unrelated files do not perturb
  identity and that release/FI-1 identities are distinct.

- **Round-5 release/board custody (2026-07-24; metadata/tooling only, no firmware
  rebuild).** The committed manifest now requires
  `supported_board_revisions: ["revD"]` and the authoritative exact tuple
  `qualified_releases: ["revD|rel-0c746b5747143b8011b01d43|05d808411db4bb0d"]`;
  `release.ps1` stamps/verifies both through `release_manifest_policy.py` and emits
  `WSL_RP2040_QUALIFIED_RELEASES` plus
  `WSL_RP2040_SUPPORTED_BOARD_REVISIONS`. Independent build/config lists are
  provenance only and cannot authorize their unsafe Cartesian product. The two
  manifest-named UF2s are
  committed as ordinary binary Git blobs, explicitly outside text conversion and LFS:
  production SHA-256
  `d5570efd19c374d9ca4532b78ef36577ae93b88160b5c1775e92d1ef88c40aae`;
  FI-1 bench SHA-256
  `7c1daabad0a102f55fa61d617d3b4f0722705770f109e2d941b5356b3378ae6c`.
  Controlled identity inputs are pinned to LF for `core.autocrlf` invariance. The
  embedded build IDs, config ID, UF2 bytes, and firmware behavior did **not** change;
  only the manifest metadata/hash changed (current manifest SHA-256
  `ea8ea4ceb273df98e888aeb5d1f1327d39577e8492fda455c932fea3768bd7b5`).
  This bundle must never be flashed on Rev-B/Rev-C, and `_FI1.uf2` remains bench-only.

- **Rev-D 47 kΩ fast-input contract.** `init_inputs()` now disables RP2040 internal
  pulls. Leaving the internal ~50–80 kΩ pull-up enabled in parallel would reduce the
  effective pull-up to ~24–30 kΩ and invalidate the new optocoupler sink-current margin.
  The external `Rpu_*` parts are authoritative; a missing pull-up is a board fault rather
  than something firmware masks. Diagnostic taps remain separate and continue using
  their 10 kΩ `Rtapd_*` drain pull-ups. `test_v12` now asserts all fast pulls are off.
  ⚠️ **Silicon-side status (audit note 2026-07-24):** every rev-C bench/field validation
  ran with 10 kΩ boards AND internal pulls enabled — the 47 kΩ/no-internal-pull input
  path exists only in host tests and margin math until the FA-9 loaded-minimum and
  hot-corner measurements pass on the assembled first article. Do not flash this build
  onto a 10 kΩ (rev-C) board expecting validated input thresholds.

**Build:** both ARM images rebuild clean (arm-none-eabi-gcc 13.3.1, 0 warnings on main.c):
release `wsl_phase8b_rp2040.uf2` (61.5 KB) + bench `wsl_phase8b_rp2040_FI1.uf2` (65.5 KB,
differently-named — release directory auditable by filename). Host suites: `test_main`
**64/64** · `test_v11` **32/32** · `test_v12` **140/140** (+21) · `test_fi1` **44/44** (+16),
all clean under `-Wall -Wextra -Werror` (gcc 16.1.0). **NOT flashed.**

## v1.2.2 — 2026-07-21 — Codex round-2 R2-1 + R2-13 (pad-OE lock, epoch classifier, FI-1, identity). NOT FLASHED.

Scope = the round-2 firmware slice of the rev-D remediation (Codex re-audit 2026-07-21 PM).
All line-format changes ADDITIVE; `rp2040_link.py` gains the matching id/rid consumption.

**Round-3 pre-flash fixes (Codex 2026-07-21 PM re-review; amended in place — this
version was never flashed, no image with the defects ever left the repo):**

- **Boot-order regression (critical).** The R2-1 contract set grew to include the fast
  inputs GP6-13, but `main()` runs its first `tap_assert_input_only()` pass BEFORE
  `init_inputs()` — at that moment GP6-13 are at silicon reset state (FUNCSEL=NULL, not
  SIO), so EVERY boot of the unfixed image latched a spurious `tap_dir`/SA fault and
  refused RP_OK until an operator PBZ. Fix: `inputs_inited` gate (same pattern as
  `rev_id_inited`) — the pre-inputs pass still enforces taps/ADC/REV_ID from the first
  moment, GP6-13 join the contract set when `init_inputs()` completes, and `main()` runs
  a second invariant pass immediately after so init-time drift still latches at boot.
  New host test `test_v12.c` section R replicates main()'s LITERAL boot order on
  reset-state pins (the old tests all ran `init_inputs()` before any assertion, which is
  exactly why 111/111 missed it).
- **16-bit epoch alias guard (minor).** Ring entries store only the low 16 bits of the
  32-bit boot epoch; after 65536 ring-adopting reboots (a persistent watchdog crash-loop
  reaches that in ~9-18 h) a surviving pre-loop edge's truncated tag aliased back to
  "current" and could stamp a wrong advisory cause code on a TAPDUMP. Fix: at ring
  adoption (`tap_boot_init`), any entry whose 16-bit tag collides with the NEW current
  epoch is definitionally stale (IRQs not yet enabled) and is re-tagged to previous-epoch;
  the scan runs on every adoption so nothing can age back into freshness. Host test
  section S pins the wrap, the re-tag, and that fresh edges still classify.
  `test_v12` total: 111 → **119**.

- **R2-1 — pad-level output-enable lock.** The v1.2.0/v1.2.1 input-only invariant read
  back the SIO direction + IO-bank function ONLY; the RP2040's per-pin `CTRL.OEOVER`
  field bypasses both (OEOVER=ENABLE/HIGH forces output-enable AT THE PAD with the SIO
  direction still reading input). Now: `force_pad_input_only()` (the ONE lock point,
  `gpio_set_oeover(OEOVER=DISABLE)`, called LAST in every pin-config choke point because
  `gpio_init`/`gpio_set_function` rewrite the whole CTRL register and silently clear the
  override — the mock mirrors that clearing) + `pad_oe_locked()` verifying BOTH the
  OEOVER field still reads DISABLE AND the live pad `STATUS.OETOPAD` bit reads 0, at init
  and every heartbeat tick. Coverage widened from taps+ADC to EVERY input-contract pin:
  GP16-19, GP26, fast inputs GP6-13, REV_ID GP20-21. Drift latches a fail-safe `pad_oe`
  fault (RP_OK drops). The host direction gate (`test_v12.c` section M) got the required
  **OEOVER mutation cases**: override forced HIGH (pad drives, SIO still input — the
  exact blind spot), override merely returned to NORMAL (must trip BEFORE the pad
  drives), a rogue whole-CTRL rewrite, and the same on a fast input + REV_ID pin.
- **R2-13 — epoch-aware rail-drop classifier.** `tap_classify()` now takes the dump's
  epoch and EXCLUDES cross-epoch (pre-reboot) ring entries from classification — their
  timestamps are from a different boot's ms clock, and the epoch-blind v1.2.x scan let a
  stale pre-reboot 555 fall classify (or steer) a fresh diagnosis. Stale entries remain
  in the dump as history (`tape` lines carry per-entry epochs; the Pi's own staleness
  judgment is unchanged). Host tests pin both directions: stale-only ring ⇒ `none`;
  stale ARM-fall cannot steer a fresh-epoch `kick_starvation`.
- **R2-13/R1.9 — FI-1 bench fault-injection hook (⛔ NEVER a release artifact).**
  Compile-flag gated: `FI1_ENABLED` default 0 ⇒ ZERO FI-1 code in a release image (the
  `FI1` grammar does not exist; pinned by test_v12 section Q). The bench image (CMake
  `-DFI1_BUILD=ON`) builds to a DIFFERENT artifact name (`wsl_phase8b_rp2040_FI1.uf2`),
  compiles `fi1_bootsel.c` (BOOTSEL physical-jumper gate: booted without the jumper ⇒
  PERMANENT `fi1_nojumper` fault re-latched past CLEAR, all FI1 commands answered
  `refused`), and requires `FI1 ARM` before `FI1 DRIVE <0-3>` drives one tap output-high
  for the FA-7 unidirectionality proof (`FI1 RELEASE` restores + re-verifies the locked
  contract). Driven pin is invariant-exempt while driving; all other pins stay enforced.
  New host binary `test/test_fi1.c` (28/28) proves all three gates.
- **R2-6 — identity line.** REV_ID strap read on GP20/GP21 (encoding per the committed
  netlist generator: `REV_ID[1:0] = GP21<<1|GP20`, rev-D = 0b01) with a pull-phase
  floating detector — internal pull-down read, then pull-up read; a 10k strap wins both,
  a floating (rev-B/rev-C) pin follows the pull ⇒ reads differ ⇒ `REV_ID_FLOATING`
  reported "unknown", never assumed rev-D; pulls disabled after the read (zero static
  current) and the pins join the invariant contract set. New additive
  `{"ev":"id",fw,pcb,rid,uid,build,cfg,fi1,t}` line (after boot + on the new `ID`
  command): strap-read PCB rev, Pico unique id (`pico_unique_id`), build identity
  (`build_id.h`, regenerated EVERY build by `gen_build_id.cmake`: `git describe
  --always --dirty` + sha256(config.h)[:8]; host/fallback = "unknown"), FI-1 posture.
  hb gains `rid` every beat. Pi-side: `rp2040_link.py` consumes both (stored +
  `fw_identity()`/`pcb_rev_id()` accessors + typed `fw_identity` diag record; an
  `fi1:1` image is logged as an ERROR — never allowed at a lane).
- **Capacity re-budget:** hb worst ~184 B (rid), id worst ~190 B (capped `%.Ns` fields);
  fmtbuf 256 holds; `TXR_HEADROOM` 288 → 320 (worst flt+rp_ok+hb burst ~284 B).
- **Safety-critical paths untouched:** the only new fault sources are `pad_oe`
  (fail-safe direction) and the FI-1-build-only `fi1_nojumper`. RP_OK-LOW-first boot
  ordering retained; REV_ID read happens before the boot line so identity is coherent
  from the first emission.
- **Verification:** host tests **64/64** (`test_main`) + **32/32** (`test_v11`) +
  **111/111** (`test_v12`, +40 for R2-1/R2-13/R2-6) + **28/28** (`test_fi1`, new), all
  0-warning under `-Wall -Wextra -Werror` (gcc 16.1.0). Clean ARM cross-builds:
  release `.uf2` = 60.5 KB (build_id.h verified: real git hash + config sha embedded;
  `.map` confirms `tap_ring` still in `.uninitialized_data`) and FI-1 bench
  `wsl_phase8b_rp2040_FI1.uf2` = 63 KB. Pi-side: `rp2040_link.py` self-test **45/45**,
  `tests/test_rp2040_link.py` 93/93, new `tests/test_fw_identity_line.py` (6), full
  lane-node pytest suite green.
- **Bench gates (host tests CANNOT prove):** BOOTSEL read on real silicon (flash-CS
  float window), REV_ID strap levels vs the real 10k/internal-pull divider, OEOVER
  behavior on real pads (FA-7 step 2 measures the nets), and everything already listed
  under v1.2.0.

## v1.2.1 — 2026-07-21 — TAP_KICK_STARVE_MS corrected 300 → 2000 ms. NOT FLASHED.

Advisory-classifier fix (post-remediation review finding vs the C2 work; no safety path
touched, no line-format change):

- **`TAP_KICK_STARVE_MS` 300 → 2000 ms.** The v1.2.0 value was sized against a "~250 ms
  Pi kick cadence" that does not exist — that figure was `HB_INTERVAL_MS` (the RP2040
  heartbeat) mistaken for the Pi's kick period. The real kick source
  (`lane_node/lane_node.py` `watchdog_kick_loop()`) runs at 1 Hz (50 ms HIGH / 950 ms
  LOW), so consecutive kick EDGES from a perfectly healthy Pi arrive up to ~950 ms apart
  and the 300 ms threshold classified ~65 % of genuine live-kick-train `555_drop` events
  as `kick_starvation`, misdirecting post-mortems toward the Pi/kick path. 2000 ms = two
  fully missed 1 Hz kick periods: a live train can never trip it; a dead train always
  does, far inside the ~11 s NE555 window. The config.h comment now derives the value
  from the real cadence and states both first-article VERIFY bounds (measured NE555
  window ≫ 2000 ms; observed kick edge spacing < 2000 ms).
- **Host test:** section G(a) now simulates the REAL 1 Hz kick cadence (previously
  100 ms pulses — which is why the wrong constant passed), and a new G(a2) regression
  check pins that a 555 fall landing in the normal ~950 ms inter-kick gap classifies as
  `555_drop`, NOT starvation (fails against the old 300 ms value). Suites now
  **64/64 + 32/32 + 71/71**, still `-Wall -Wextra -Werror`-clean.

## v1.2.0 — 2026-07-21 — rev-D diagnostic taps (remediation spec R3; closes Codex C2). NOT FLASHED.

Scope = exactly `docs/phase8_revD_remediation_spec_2026-07-21.md` §R3 (the binding
contract). Rev-D board only: on rev-B/rev-C, GP16-19/GP26 are unconnected (tap telemetry
is floating-pin noise there; the IRQ storm guard keeps that harmless).

- **Input-only init as an ENFORCED invariant (C2's exact ask).** `tap_init()` is the
  single choke-point configuring GP16-19 (input, Schmitt, pulls off — board supplies the
  10 k drain pull-up) and GP26 (ADC). `tap_assert_input_only()` reads BACK the SIO OE +
  IO-bank function registers at init and every heartbeat tick and `latch_fault("tap_dir")`s
  on drift — a board whose tap pins can drive is refused RP_OK. Host test `test/test_v12.c`
  is the direction-invariant gate: the mock SDK records every output-direction/write call
  per pin and the build FAILS if GP16-19/GP26 ever appear in one, across init + normal
  operation + every fault path; a second test tampers the mock OE register and asserts the
  readback trips.
- **Inverted tap decode (R3.1).** The rev-D 2N7002 common-source stages invert: raw pad
  LOW = observed net HIGH. `tap_read()` is the ONE inversion point; every wire-reported
  tap state is post-inversion observed-net truth. GP16=NE555_OUT, GP17=WDOG_KICK,
  GP18=ARM_PERMIT, GP19=RP2040_OK.
- **Rail-drop edge ring with reboot persistence (R3.3).** Both-edge GPIO IRQs on the four
  taps, 1 ms timestamps, 128-entry ring `{t_ms, pin, level, epoch}` in a
  `__uninitialized_ram` section (verified in the .map: `.uninitialized_data.tap_ring`,
  outside crt0's zero-fill). Boot: valid magic pair ⇒ ring ADOPTED + epoch increments
  (+ `wdt_reset` boot-reason capture); invalid ⇒ zeroed (true power loss). Cleared ONLY
  by the new `TAPCLR` command, never by reboot. New `TAPDUMP` command emits a header
  (`tapdump`: depth, epoch, boot reason, muted-IRQ mask, advisory cause code) then drips
  `tape` entries into TX headroom — an explicit free-space check means a dump can never
  starve hb/flt. Advisory cause codes from edge order: `kick_starvation` (kick train
  stops, then NE555_OUT falls), `arm_drop` (ARM_PERMIT fell first), `self_health`
  (RP2040_OK fell first), `555_drop` (555 fell despite a live kick), `none`.
- **GP19 self-observation cross-check (R3.1).** Tap-observed RP2040_OK vs our own GP2
  drive; 2 consecutive mismatched heartbeat ticks ⇒ rate-limited `tapwarn` line.
  Escalation to a latched fault is COMPILED OFF (`TAP_RPOK_FAULT_ENABLED=0` default —
  same posture as the v1.1 flags; also keeps a floating rev-C GP19 from nuisance-faulting).
- **VCC_5V ADC (R3.4).** GP26/ADC0 sampled at 10 Hz; hb carries latest + min/max mV over
  the hb window (250 ms sag events visible). Nominal 3.30 V ref + exact /2 divider
  assumed — first-article calibrates vs DMM at TP1 (±3 % gate).
- **IRQ storm guard.** Over 64 edges/100 ms on one tap mutes that tap's IRQ for 1 s
  (telemetry-only loss, reported in the tapdump header) — a floating/oscillating pin can
  never starve the safety loop.
- **Line formats (all additive):** hb gains `tap`/`rd`/`ep`/`v5`/`v5n`/`v5x`; boot gains
  `tap:{ep,pre,n}`; new `tapdump`/`tape`/`tapdump_end`/`tapwarn` events; new `TAPDUMP`/
  `TAPCLR` commands (unknown lines were already ignored). Verified against the real
  `rp2040_link.py`: self-test 38/38 unchanged, all v1.2 lines parsed/ignored cleanly with
  health state intact — no Pi-side change required.
- **Capacity re-budget for the larger lines:** `fmtbuf` 160→256, `TXR_SZ` 512→1024,
  `TXR_HEADROOM` 128→288 (now covers the full worst flt+rp_ok+hb burst). Worst lines
  re-counted: boot ~183 B, hb ~174 B.
- **Safety-critical paths untouched:** motion max-run, chatter guard, RP_OK drop
  semantics, watchdog feed placement, v1.1 supervision (still default OFF) — all
  byte-for-byte logic-identical; the only new fault sources are `tap_dir` (invariant
  drift — fail-safe direction) and the compiled-off `tap_rpok`. RP_OK-LOW-first boot
  ordering retained (deliberate, documented exception to R3.2's "taps first": GP2 is not
  a tap pin and taps are input-only from reset).
- **Verification:** host tests 64/64 (`test_main`) + 32/32 (`test_v11`) + **70/70
  (`test_v12`, new)**, all 0-warning under `-Wall -Wextra -Werror` (gcc 16.1.0); clean
  ARM cross-build via `build.ps1` (pico-sdk + xpack gcc): `.uf2` = 56 KB, 32.7 KB flash /
  5.4 KB RAM. `CMakeLists.txt` gains `hardware_adc`.
- **Bench gates (host tests CANNOT prove):** real-silicon IRQ latency + noinit
  persistence across an actual watchdog/soft reboot, ADC accuracy vs DMM,
  `TAP_KICK_STARVE_MS` vs the measured NE555 window, and R1.9 steps 2-5 (unidirectionality
  + fault-insertion + at-temperature + edge-order proof). The FI-1 fault-injection build
  (R1.9) is a SEPARATE, not-yet-written bench target — it must be excluded from any
  release artifact and refuse to run without its physical jumper; it is NOT part of v1.2.

## v1.1.1 — 2026-07-06 — review fixes (findings 37/56/58). NOT FLASHED.
Boot `v11` enforcement-posture field; cam-stop grace arms on FIRST trip only; chatter
guard became a true sliding window. Pi-side: hb `run`-mask reconciliation + `v11_posture()`.
Host tests 64/64 + 32/32.

## v1.1.0 — 2026-06-10 — v1.1 SAFETY supervision, all default OFF.
Cam-stop OVERRUN, SC/TB collision echo, motion-without-RUN — `#ifndef`-overridable flags,
per-cam UNCONFIRMED trip edges; a stock build enforces exactly v0.2.0. Host tests 61/61 + 28/28.

## v0.2.0 — 2026-06-10 — audit hardening.
RX overrun whole-line discard, duplicate-RUN timer guard, boot-settle latch across the
uint32 ms wrap, per-input chatter fault, TX headroom for critical lines, oversized-emit
whole-line drop, hb `in`/`run` masks, boot `maxrun_ms`/`dbg`.

## v0.1.0 — 2026-06-03 — initial firmware.
8 fast inputs debounced → UART edge events; RP2040_OK fail-safe rail permission;
hardware watchdog; motion max-run backstop; heartbeats. Verified cross-build + host test.

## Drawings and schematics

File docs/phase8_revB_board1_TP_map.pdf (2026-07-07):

# WSL Phase 8 rev-B — Test-Point Map (TPs are NOT silkscreened)

Top view (component side). Orient the board so J2 / J1 / J14 are along the TOP edge — then this map matches what you see. 1.5 mm square exposed pads.

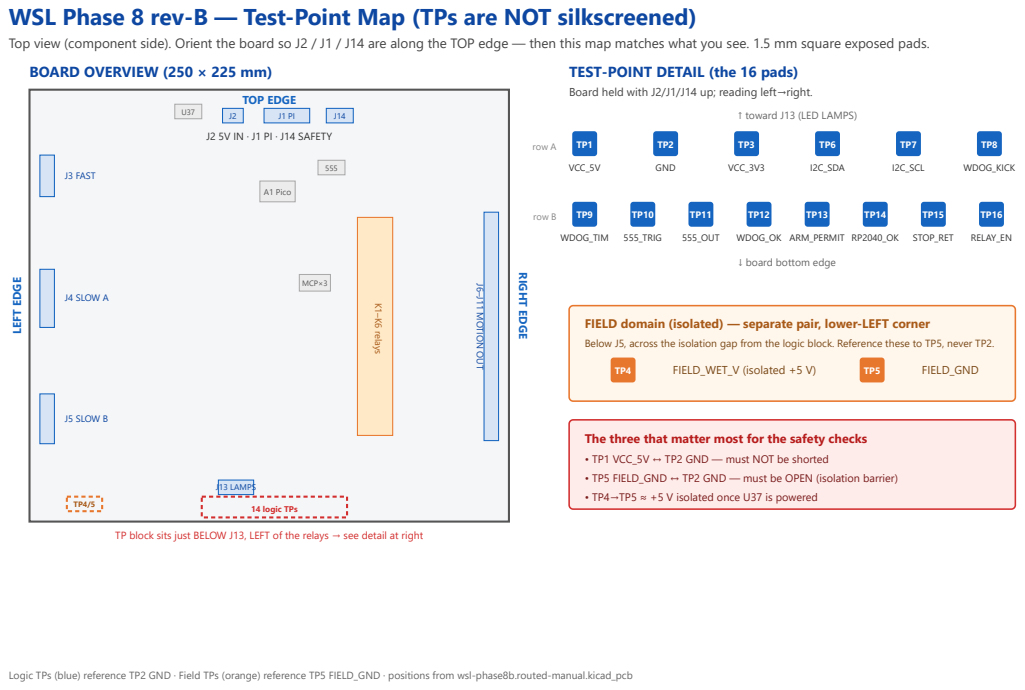
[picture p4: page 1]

TEST-POINT DETAIL (the 16 pads)
Board held with J2/J1/J14 up; reading left→right.

FIELD domain (isolated) — separate pair, lower-LEFT corner
Below J5, across the isolation gap from the logic block. Reference these to TP5, never TP2.

The three that matter most for the safety checks
• TP1 VCC_5V ↔ TP2 GND — must NOT be shorted
• TP5 FIELD_GND ↔ TP2 GND — must be OPEN (isolation barrier)
• TP4→TP5 ≈ +5 V isolated once U37 is powered

TP block sits just BELOW J13, LEFT of the relays → see detail at right

Logic TPs (blue) reference TP2 GND · Field TPs (orange) reference TP5 FIELD_GND · positions from wsl-phase8b.routed-manual.kicad_pcb

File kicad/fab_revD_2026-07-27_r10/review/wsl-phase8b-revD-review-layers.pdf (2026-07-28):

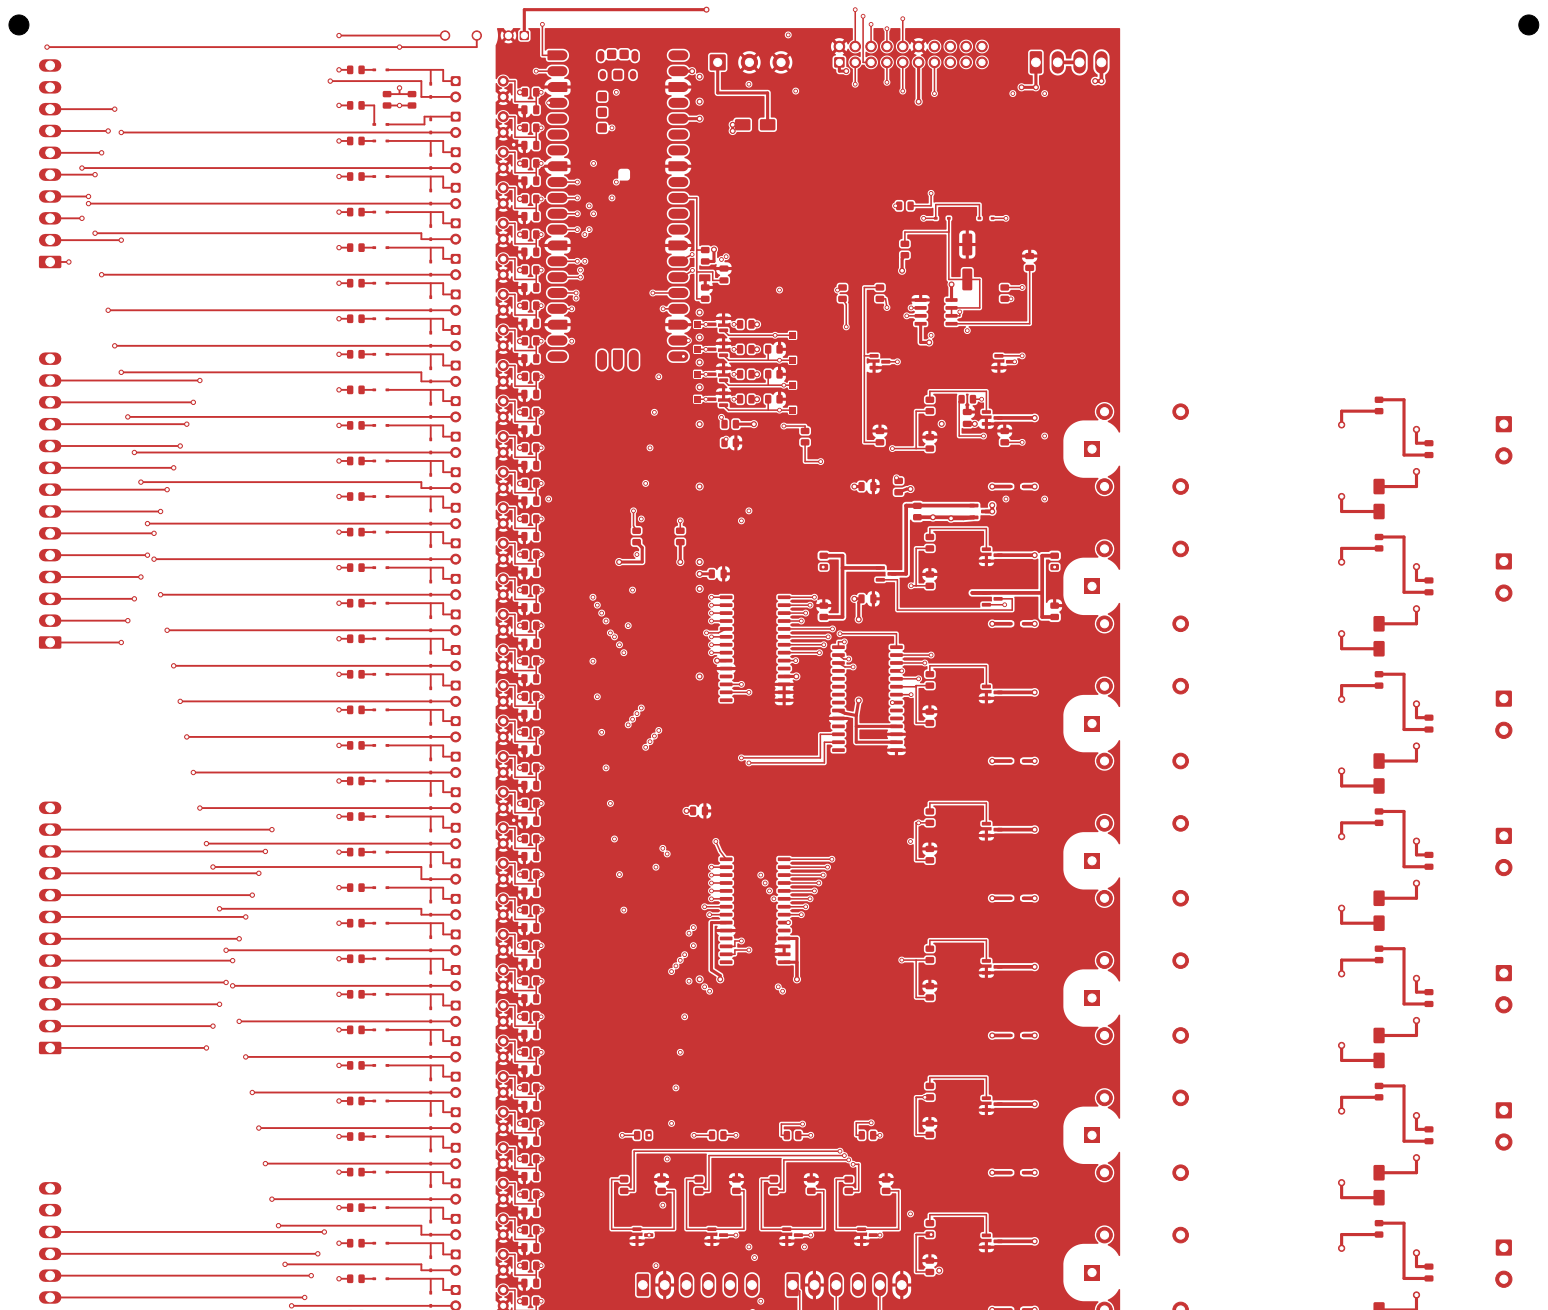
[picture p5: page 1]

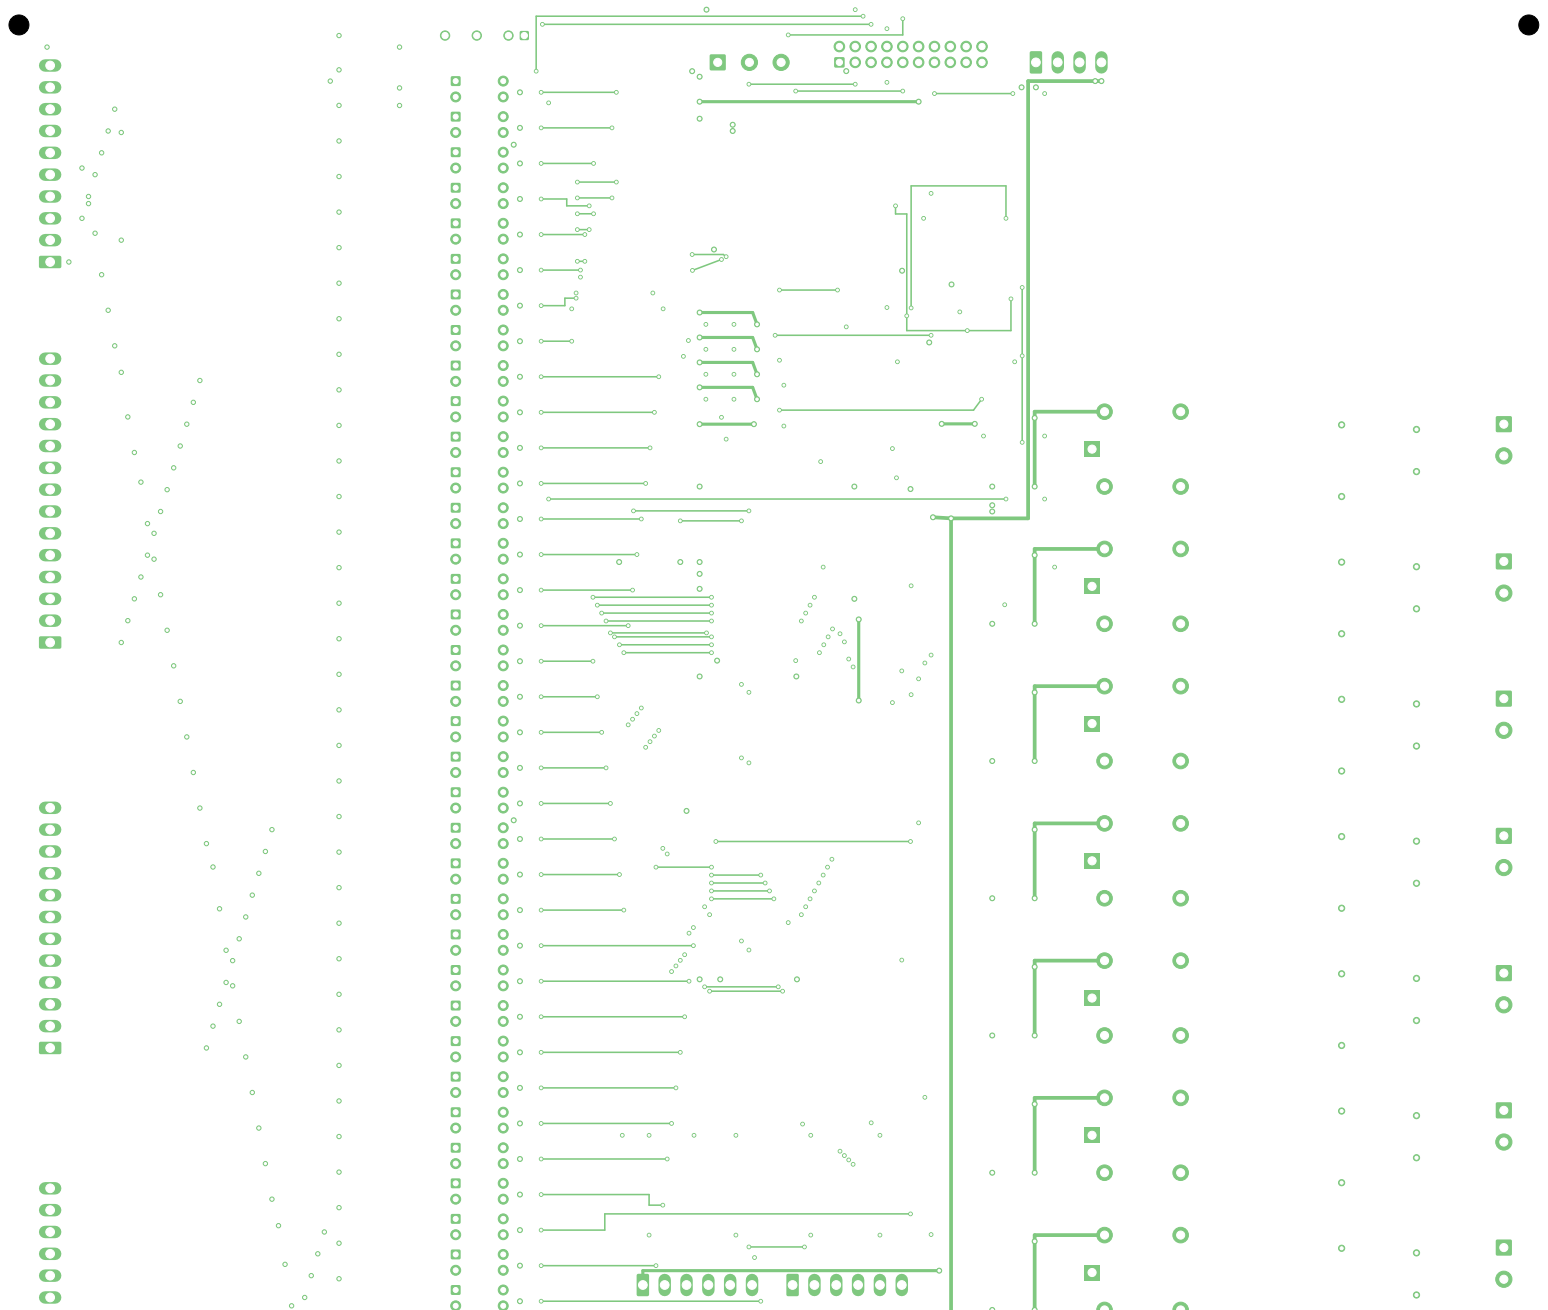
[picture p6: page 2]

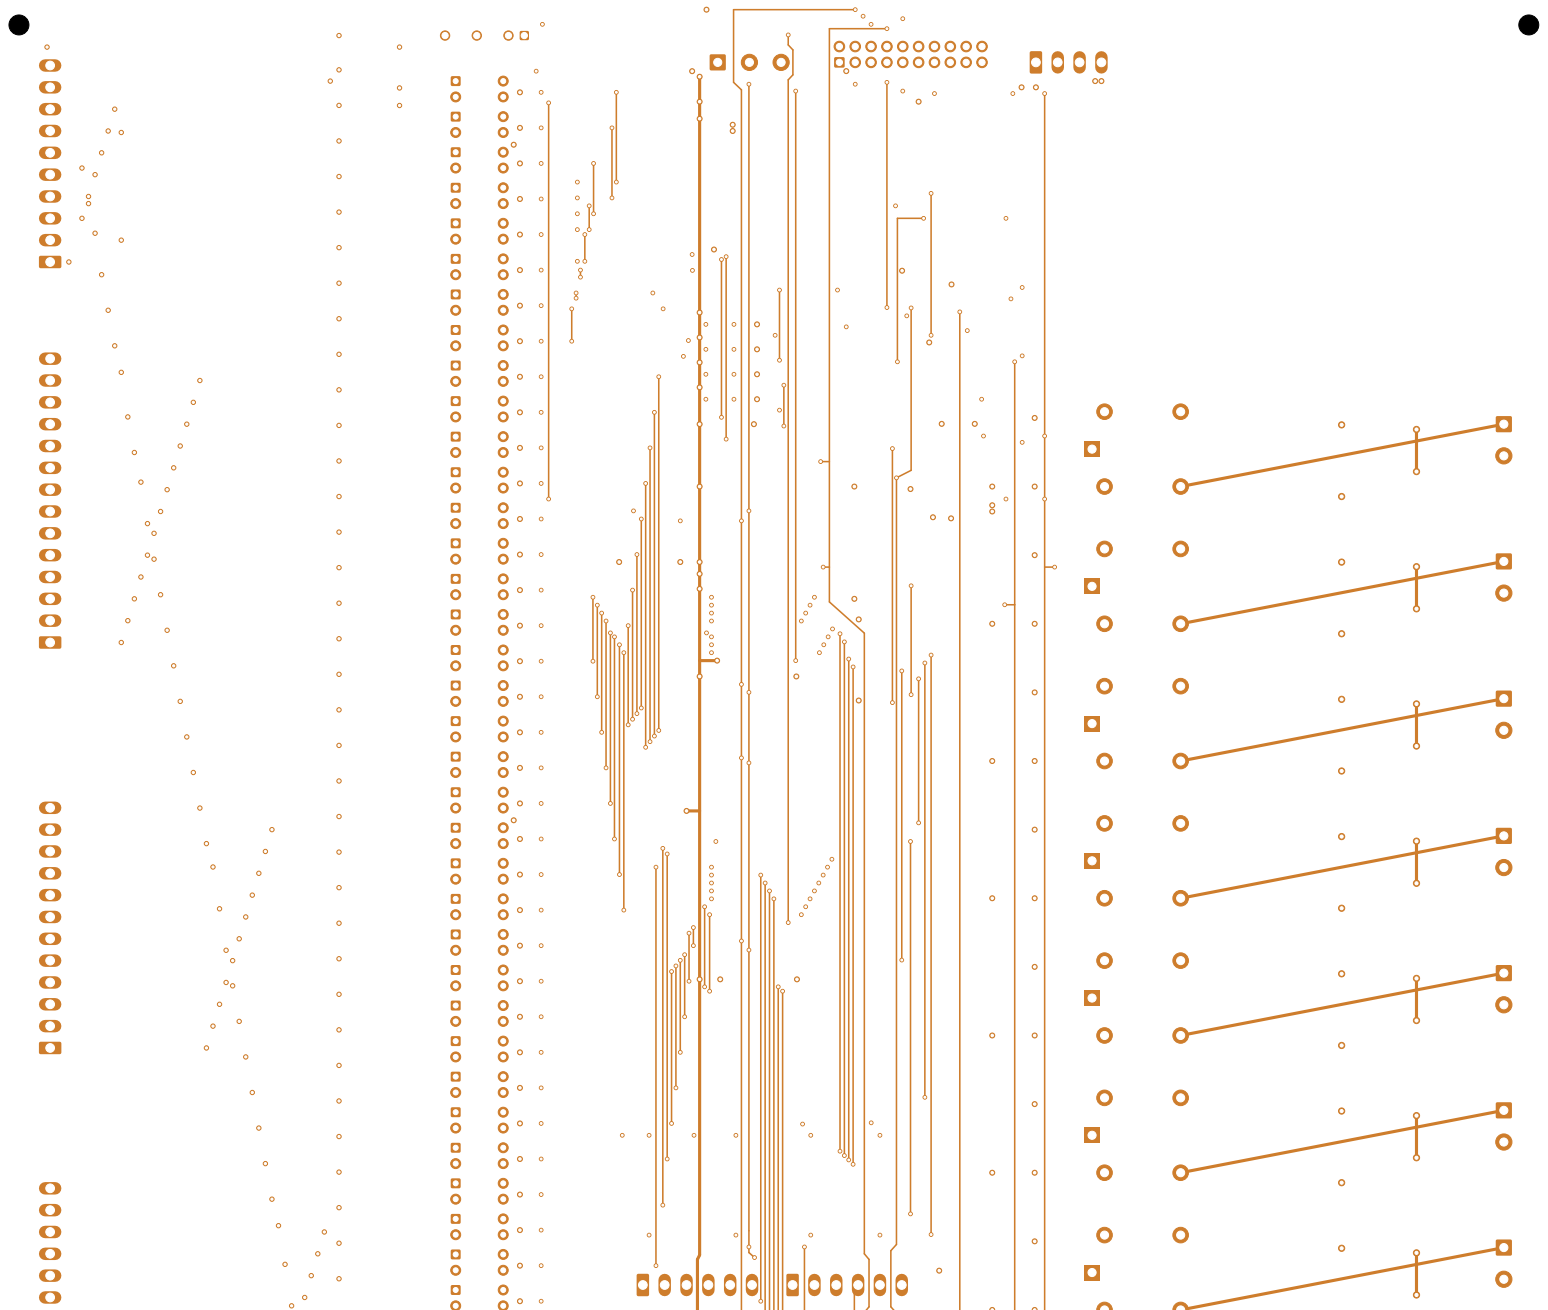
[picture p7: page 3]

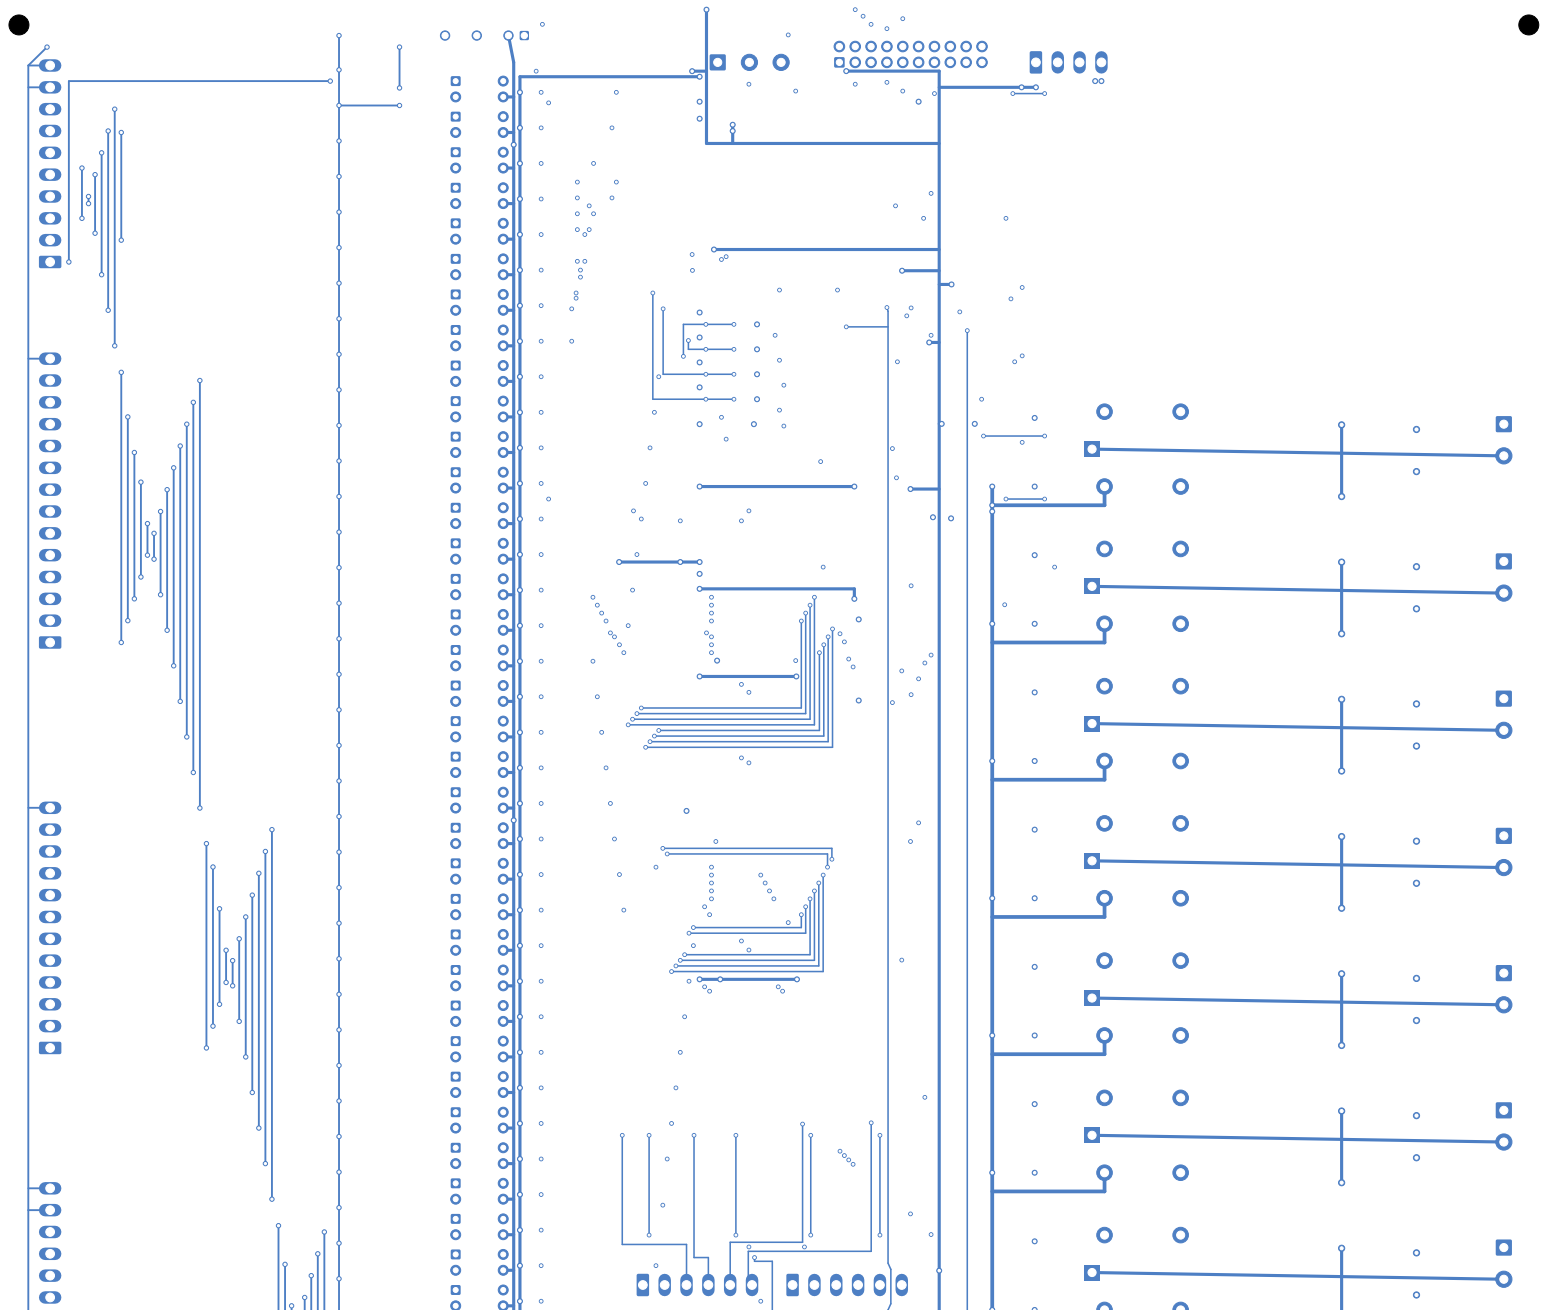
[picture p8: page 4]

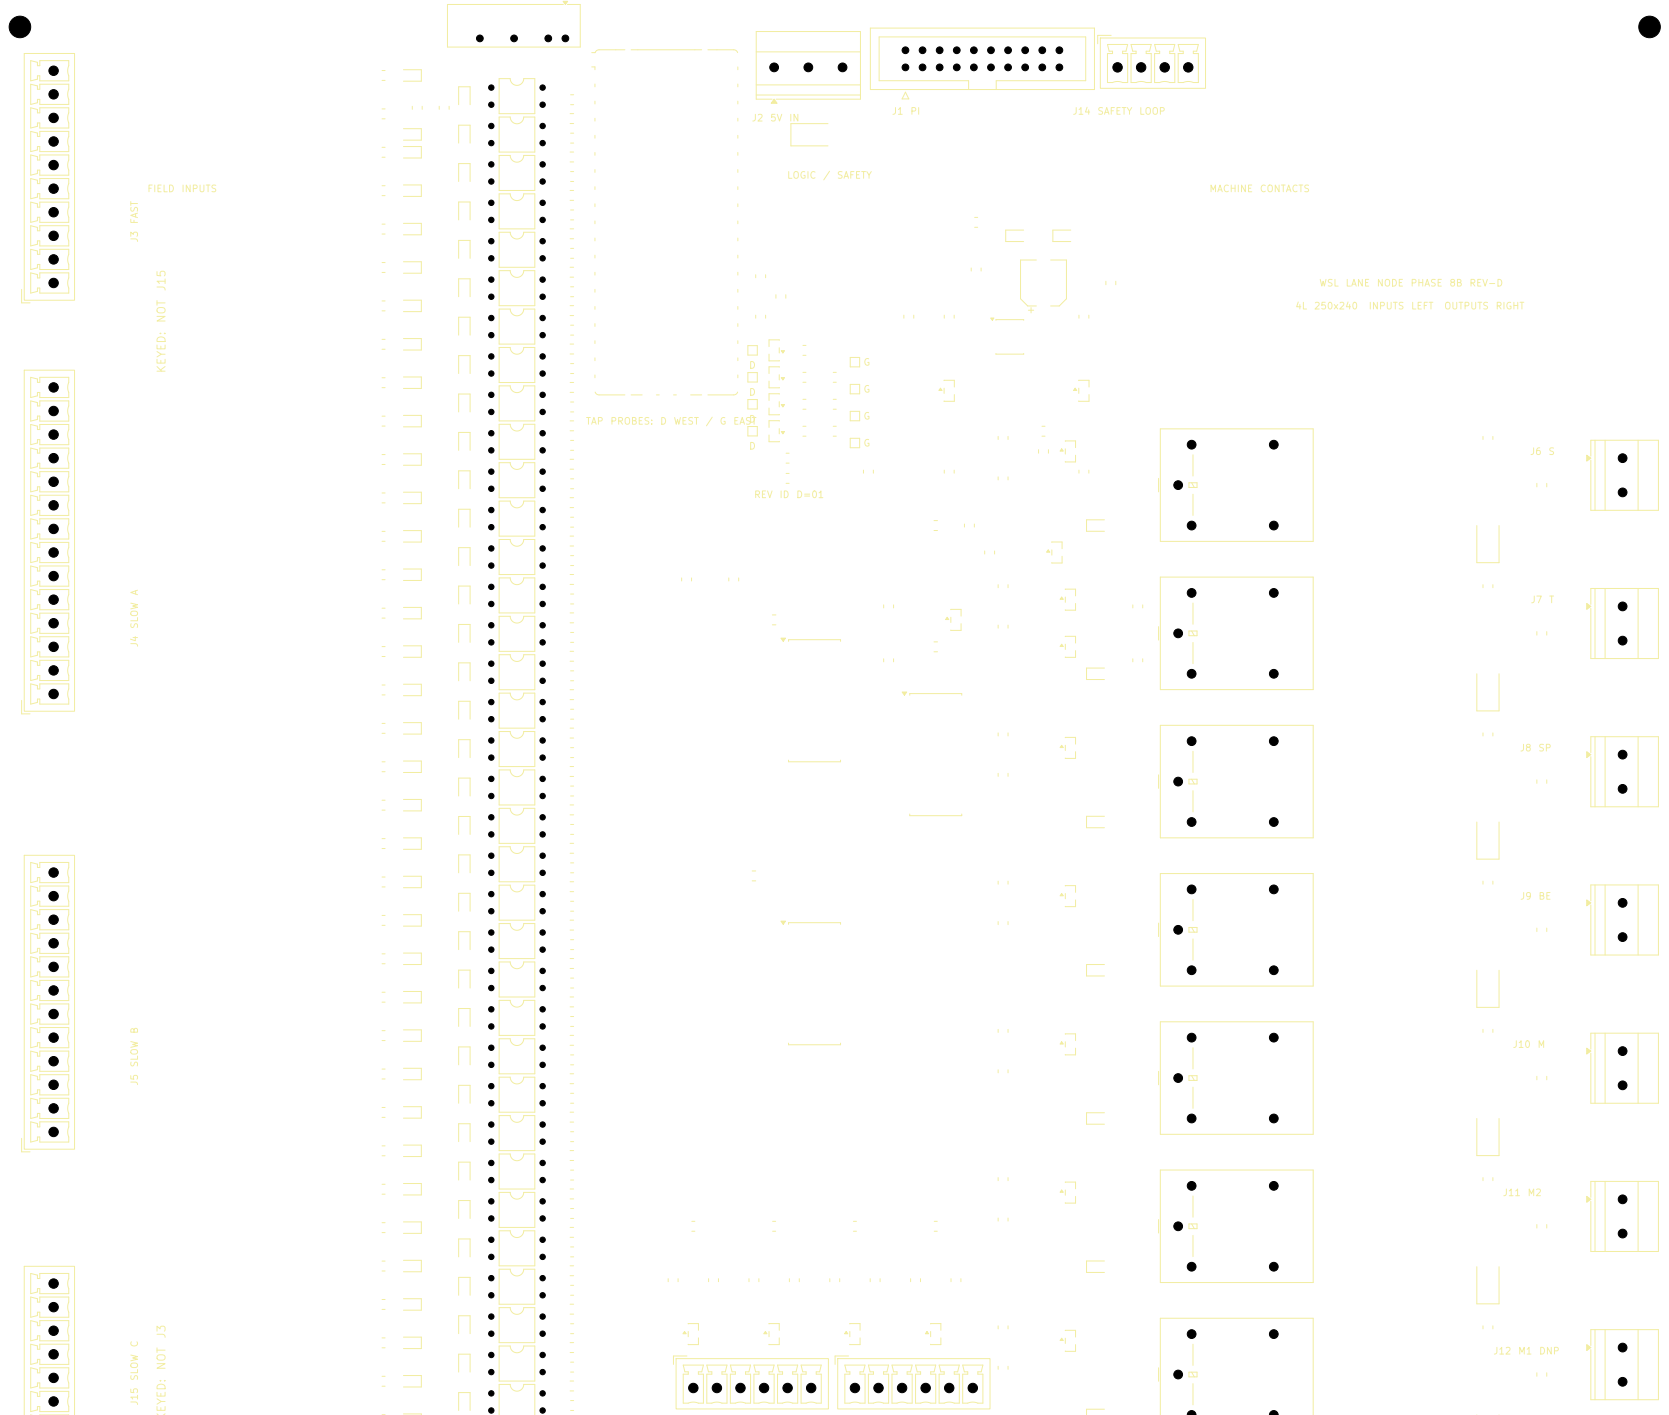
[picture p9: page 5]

4L 250x240 INPUTS LEFT OUTPUTS RIGHT

TAP PROBES: D WEST / G EAST

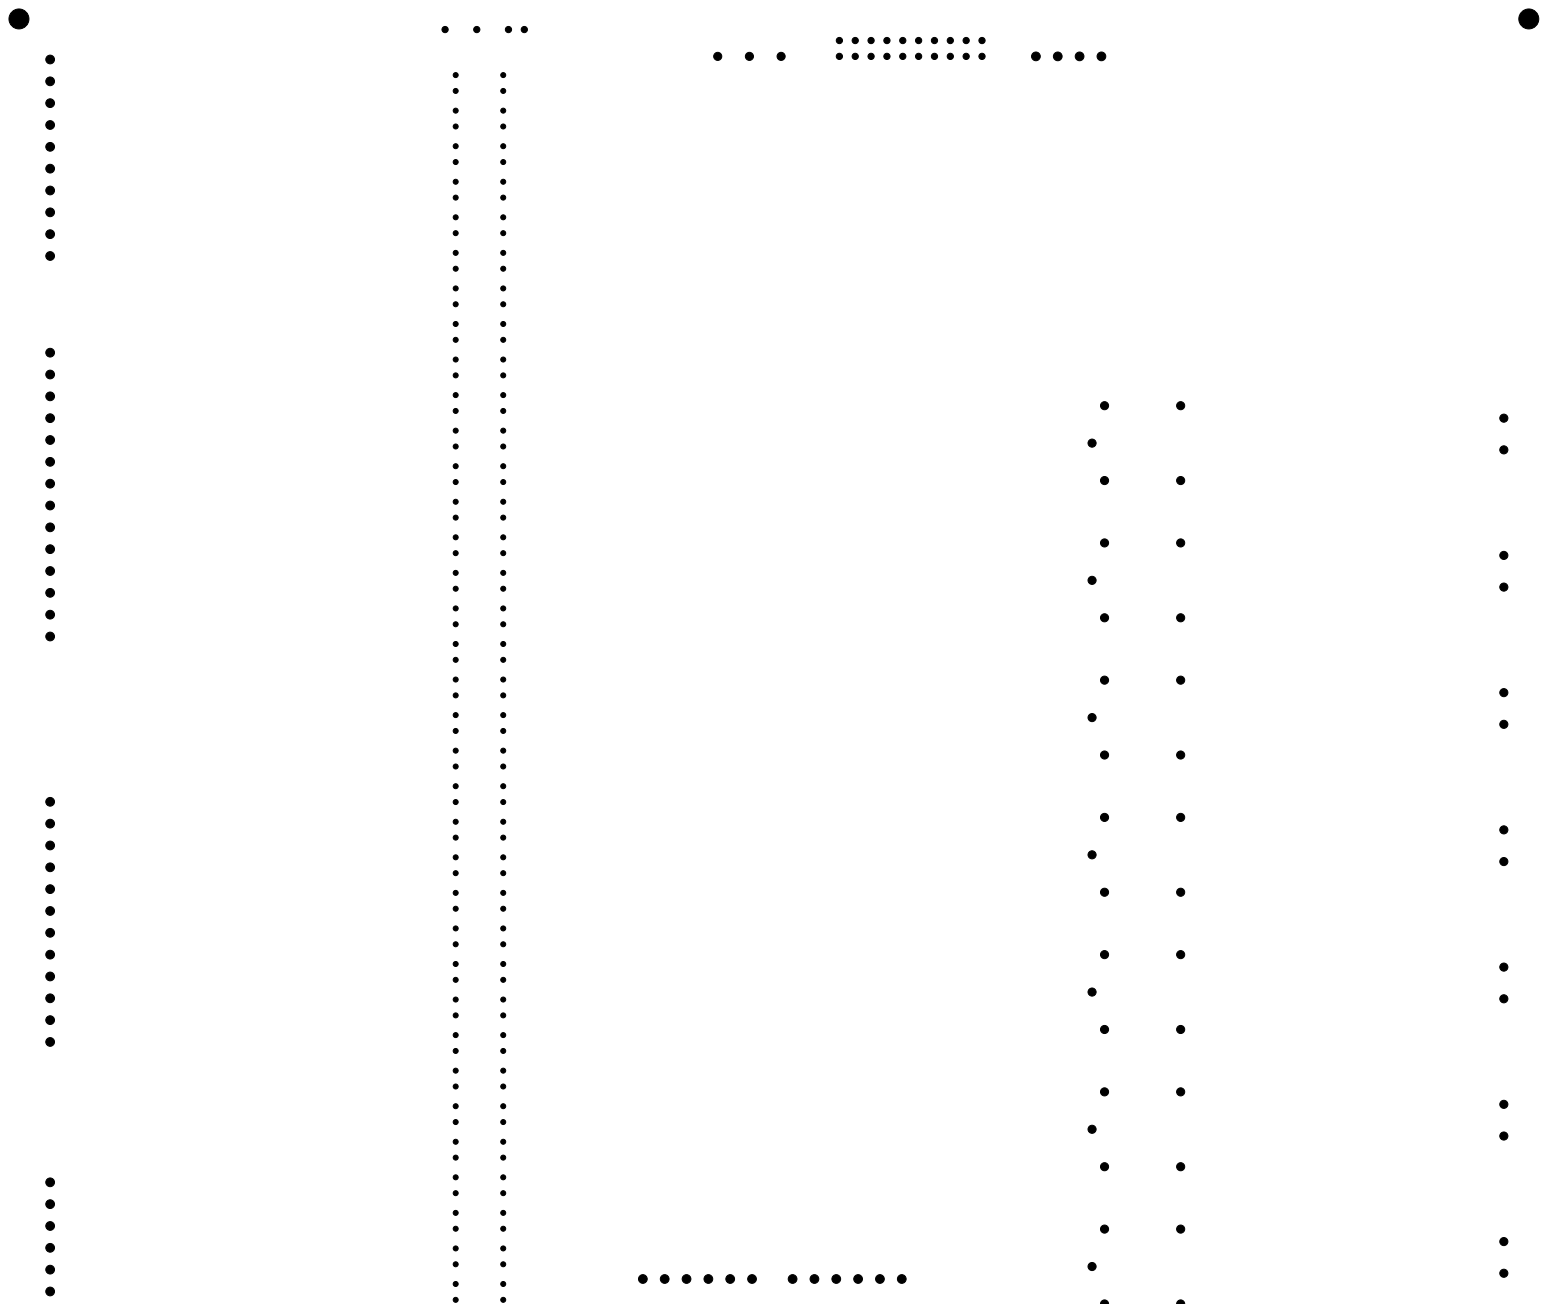
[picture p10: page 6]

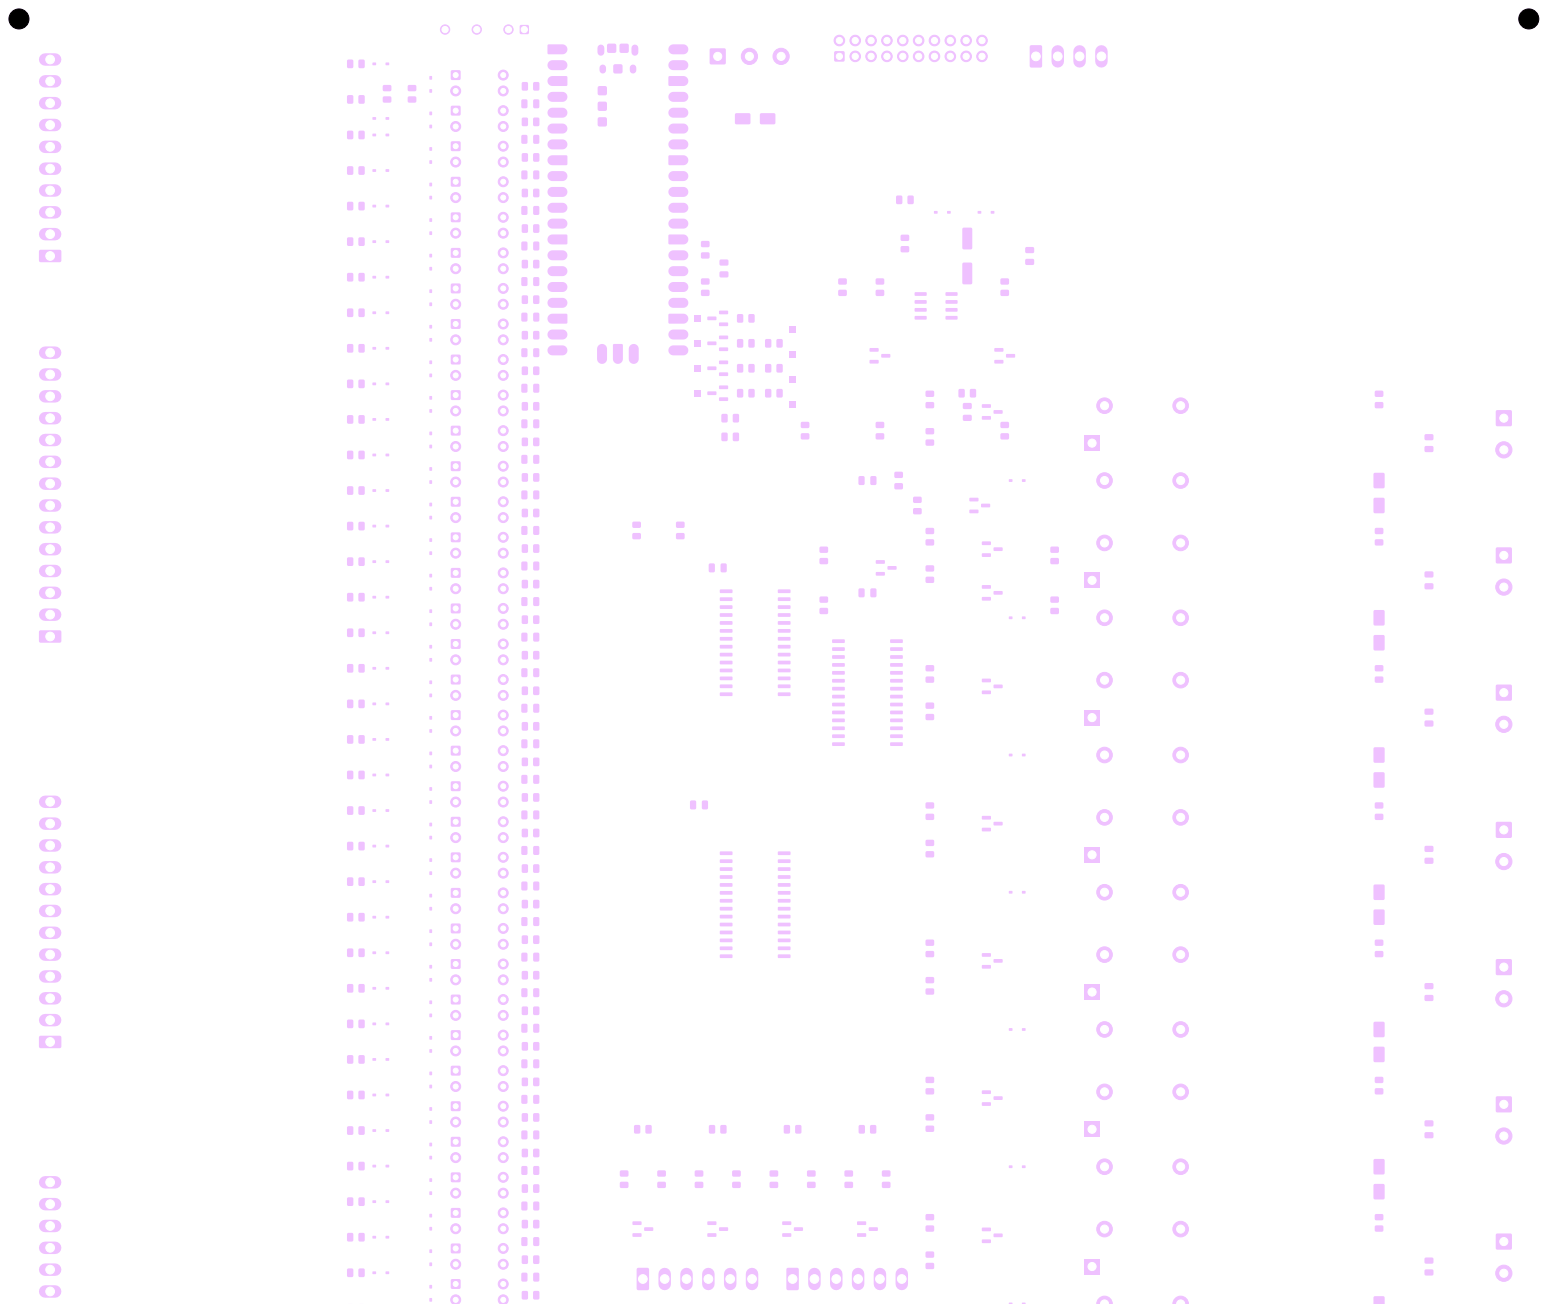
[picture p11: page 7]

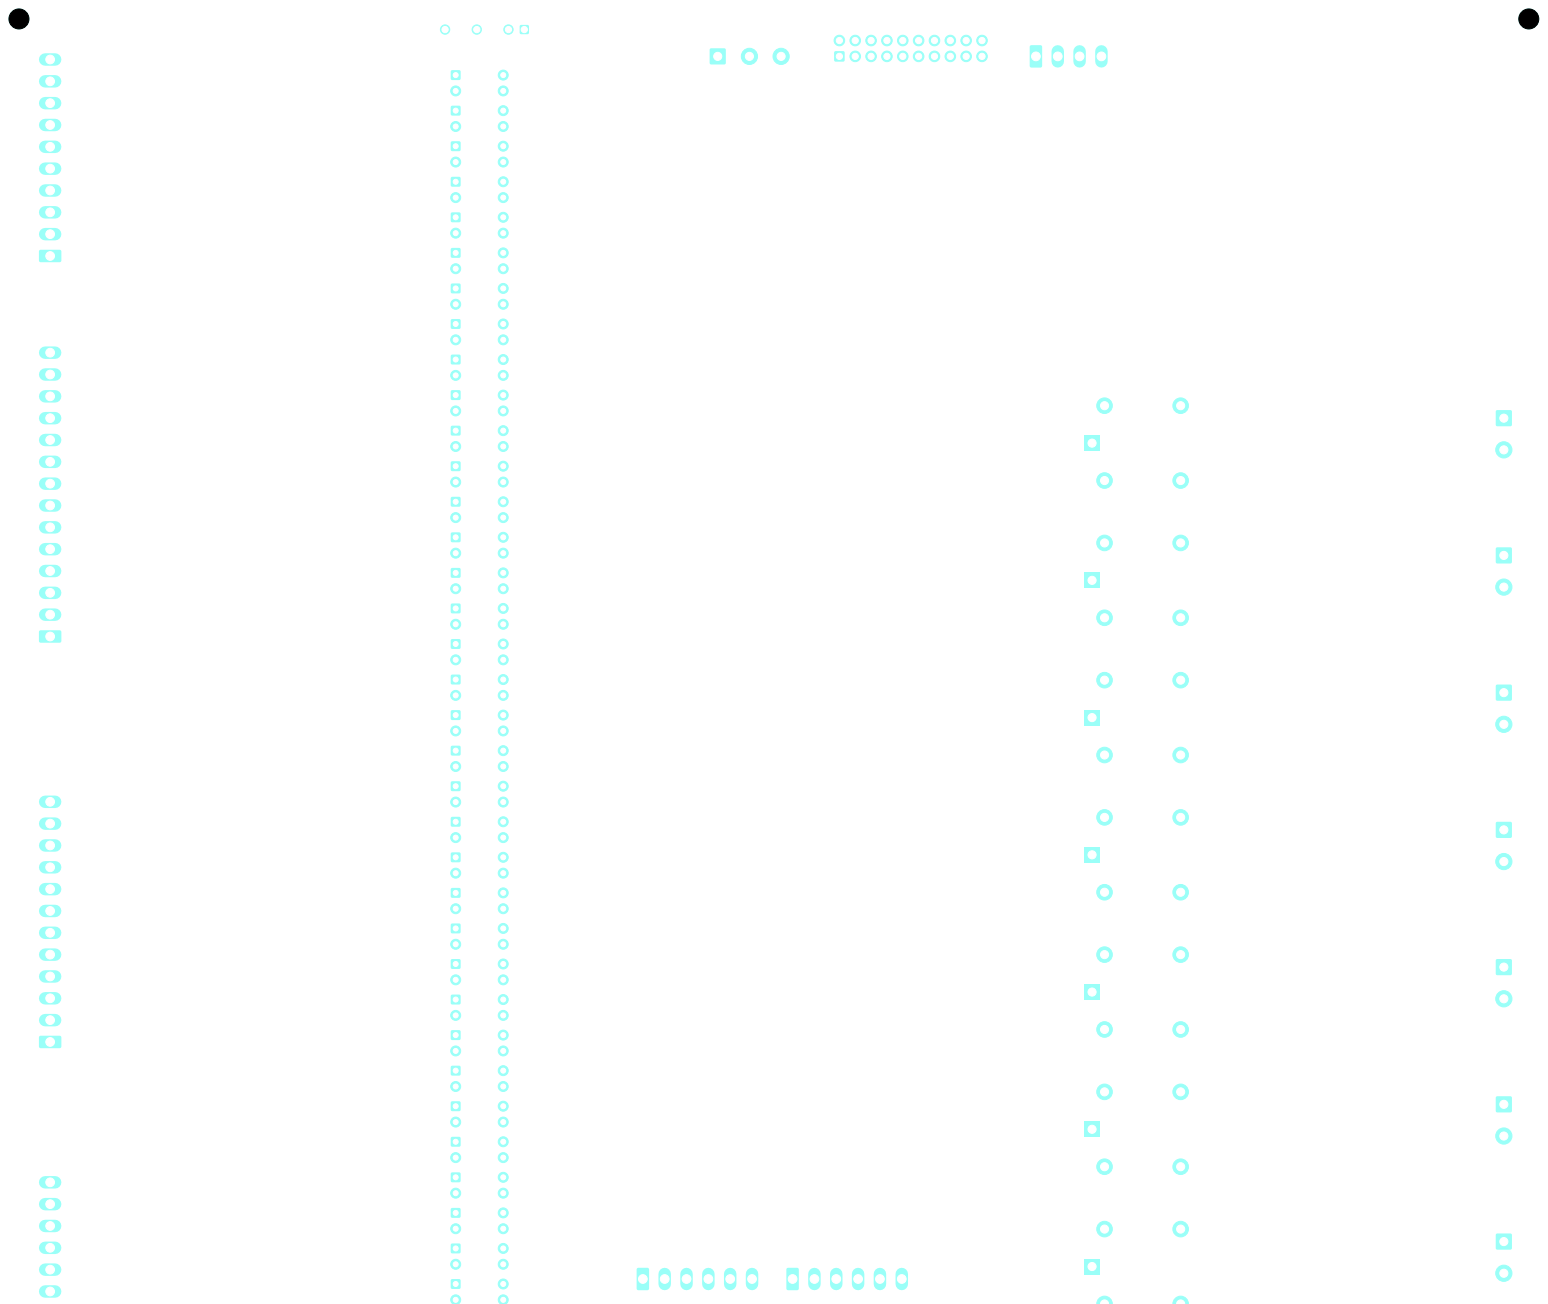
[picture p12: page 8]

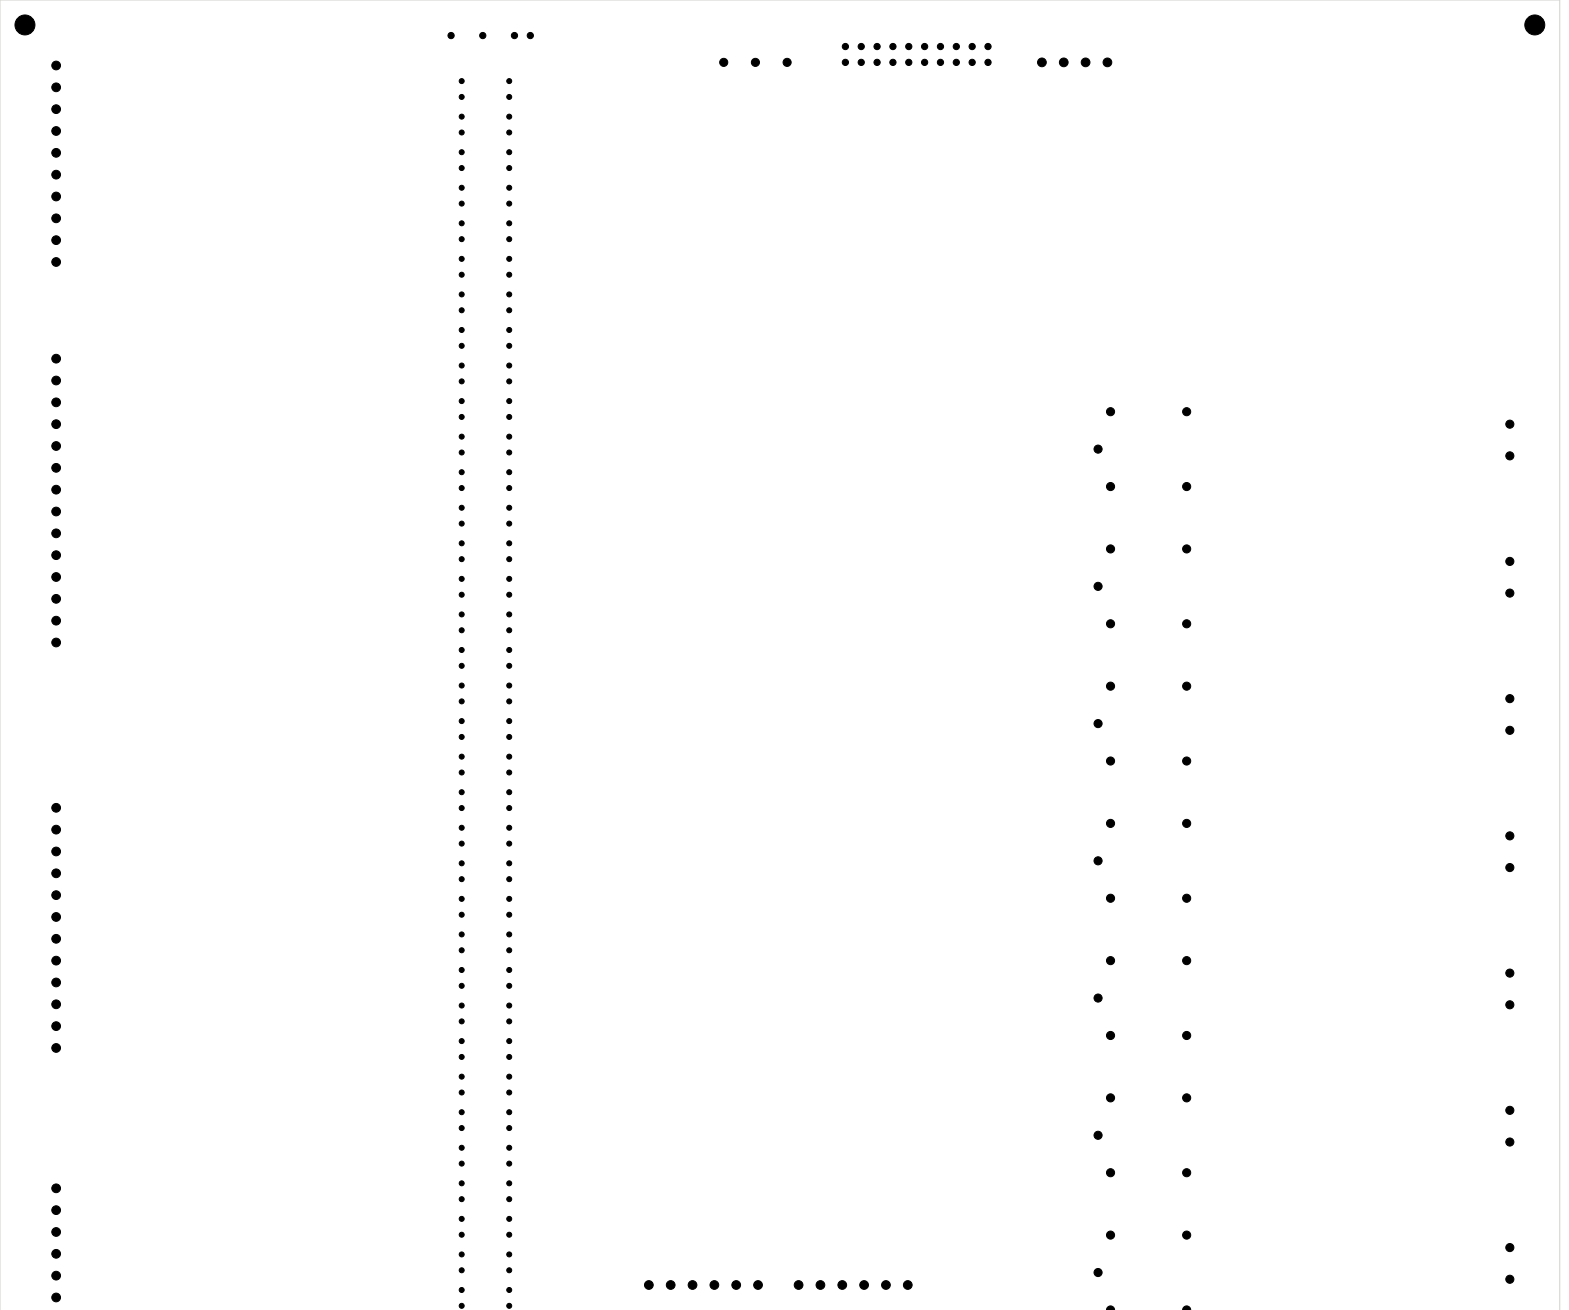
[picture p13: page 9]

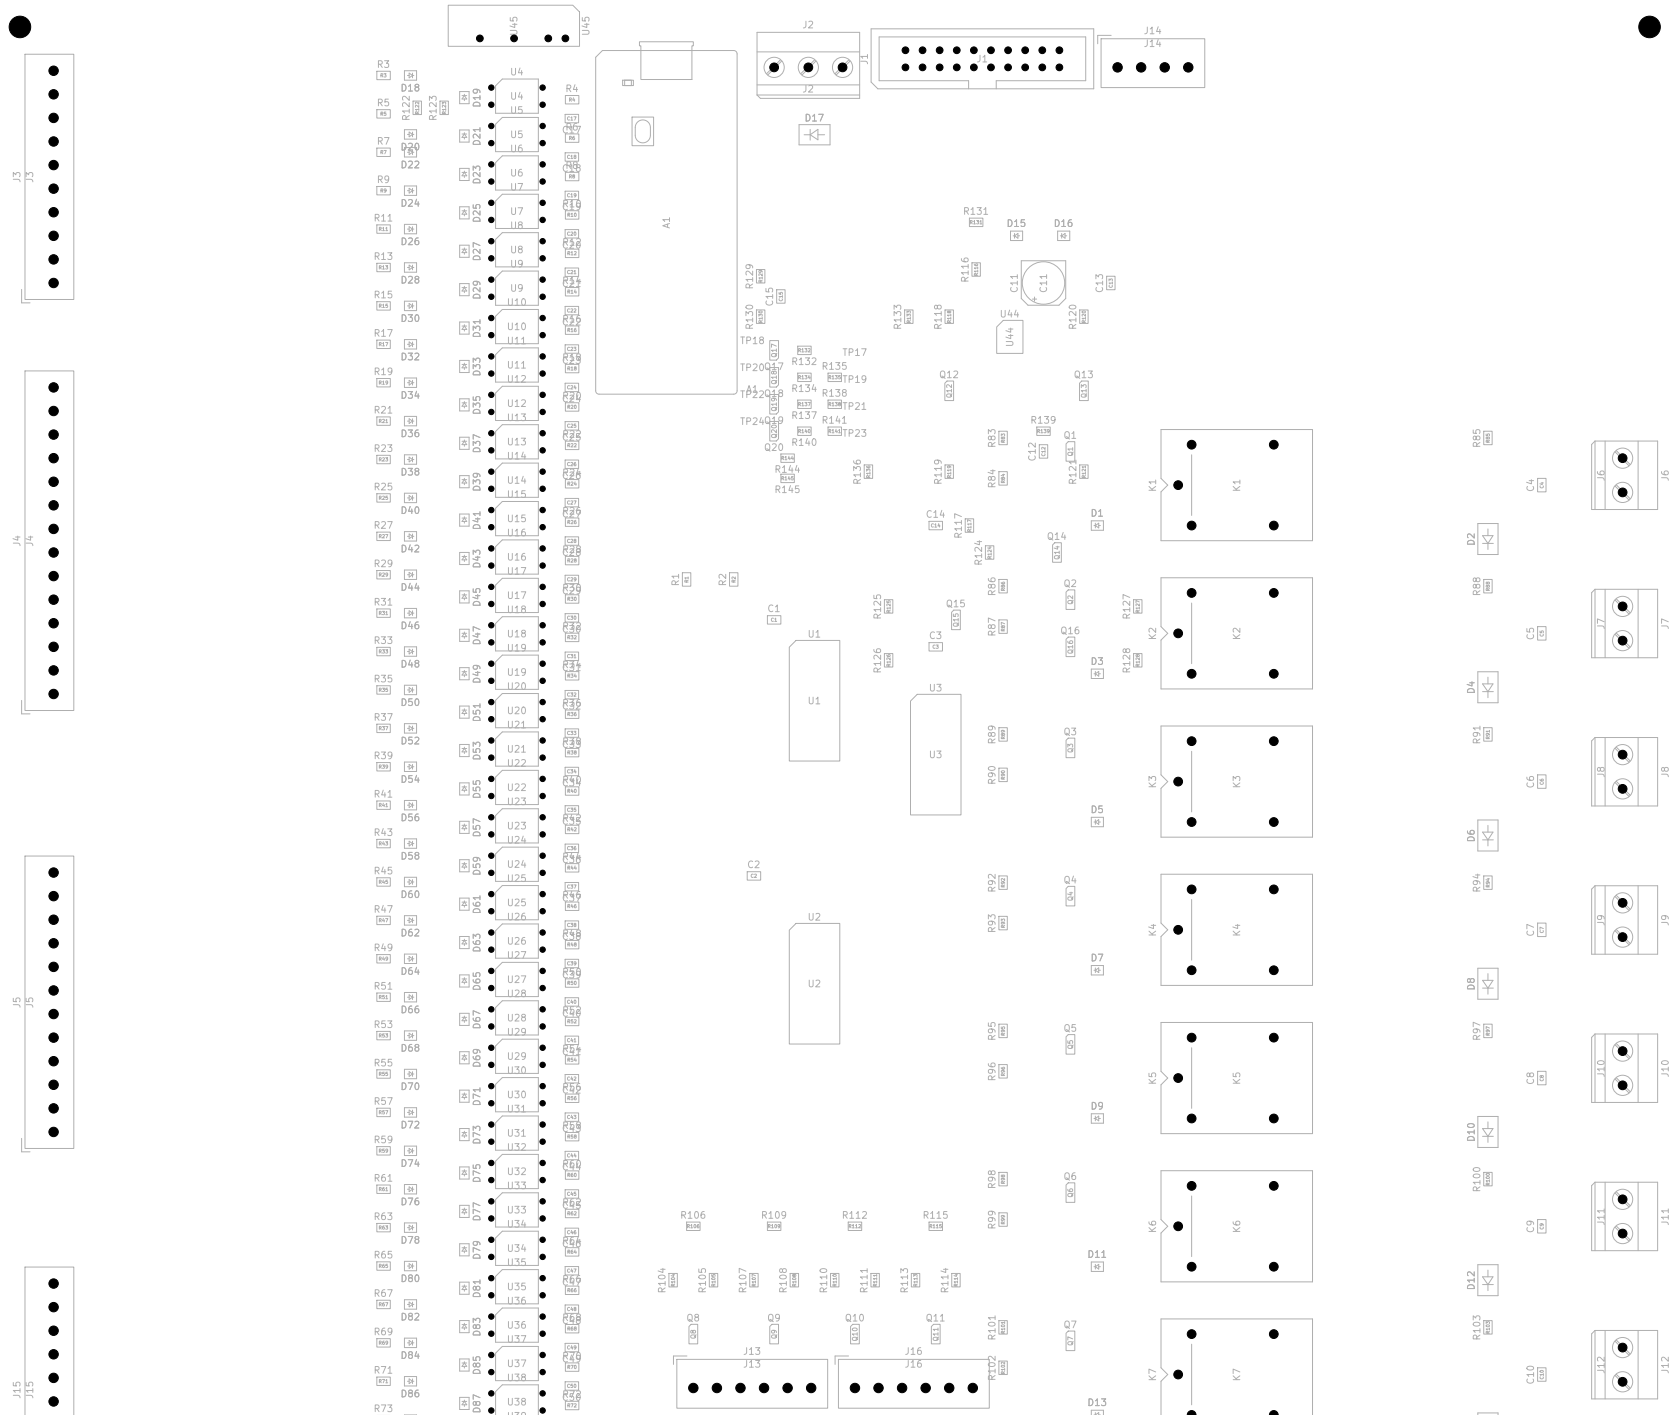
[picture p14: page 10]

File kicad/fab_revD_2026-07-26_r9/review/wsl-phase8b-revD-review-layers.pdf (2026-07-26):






4L 250x240 INPUTS LEFT OUTPUTS RIGHT

TAP PROBES: D WEST / G EAST






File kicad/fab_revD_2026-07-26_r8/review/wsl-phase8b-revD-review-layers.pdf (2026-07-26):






4L 250x240 INPUTS LEFT OUTPUTS RIGHT

TAP PROBES: D WEST / G EAST






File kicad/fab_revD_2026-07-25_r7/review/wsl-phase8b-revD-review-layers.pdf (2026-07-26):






4L 250x240 INPUTS LEFT OUTPUTS RIGHT

TAP PROBES: D WEST / G EAST






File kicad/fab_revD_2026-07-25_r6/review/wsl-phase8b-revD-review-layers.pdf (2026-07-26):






4L 250x240 INPUTS LEFT OUTPUTS RIGHT

TAP PROBES: D WEST / G EAST






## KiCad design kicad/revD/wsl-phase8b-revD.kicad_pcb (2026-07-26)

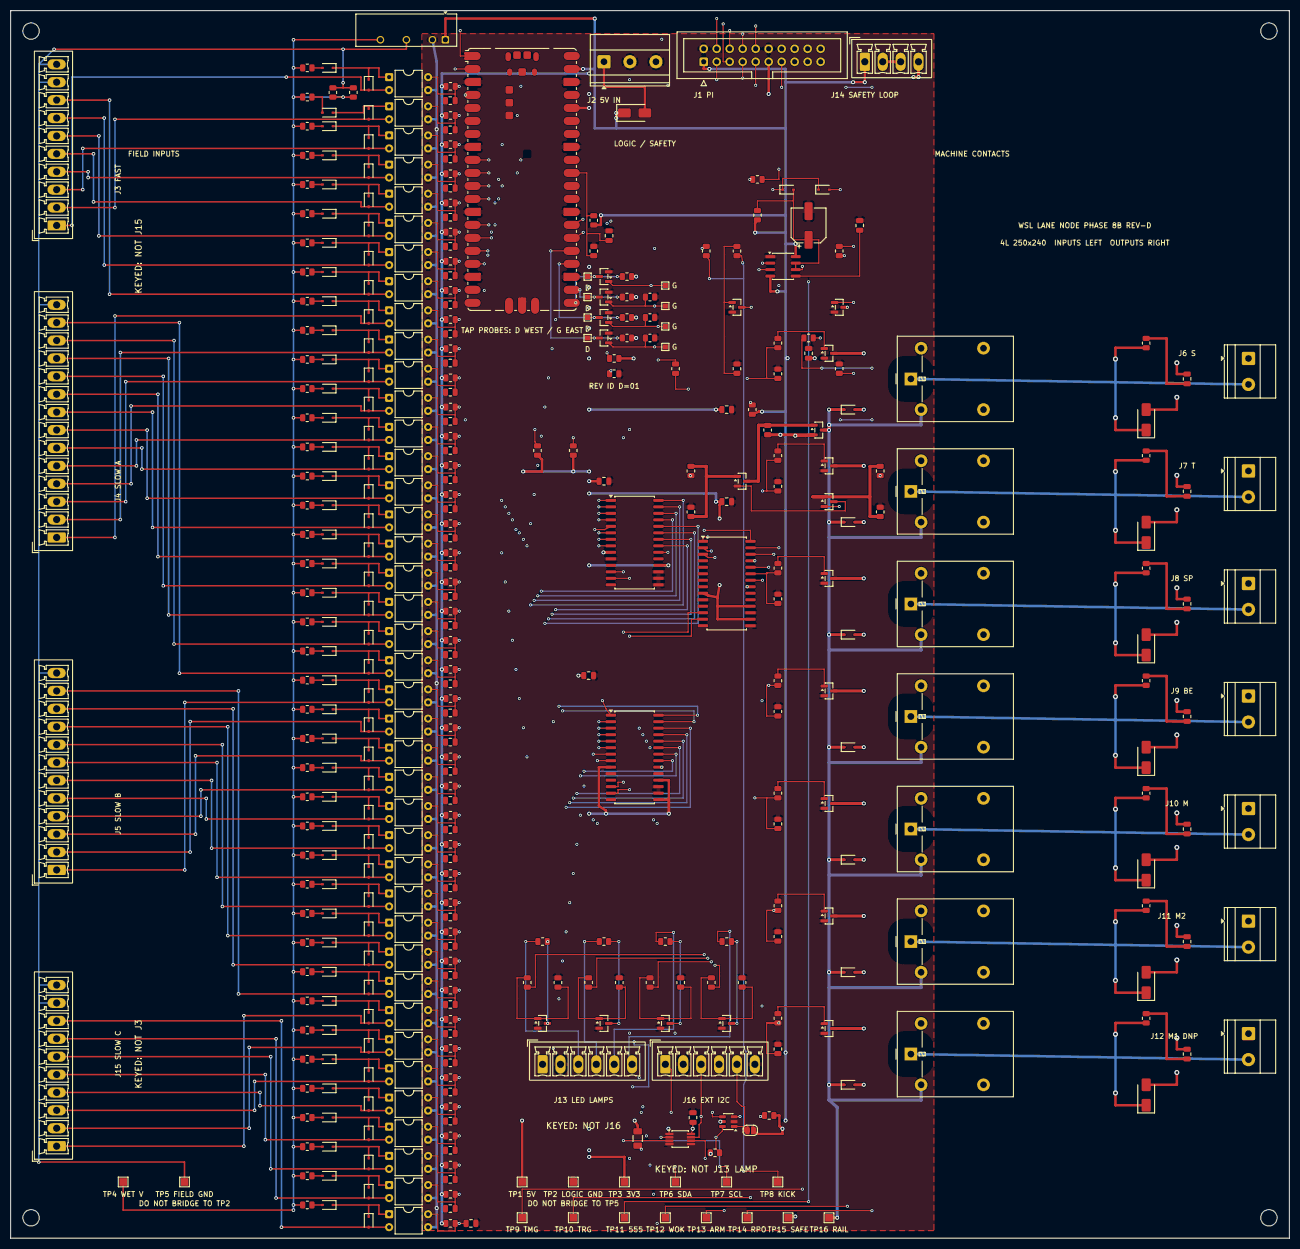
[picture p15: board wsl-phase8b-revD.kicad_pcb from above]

Board: 4 copper layers, 250.0 x 240.0 mm, 419 parts (0 on the bottom side), 263 nets.

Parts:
A1: RP2040 Pico; RaspberryPi_Pico_SMD
C1, C2, C3, C12, C16: 0.1uF; C_0805_2012Metric
C4, C5, C6, C7, C8, C9, C10: 10nF X2 DNP; C_0805_2012Metric
C11: 100uF/16V; CP_Elec_6.3x5.4
C13: 10nF; C_0805_2012Metric
C14: 10uF; C_0805_2012Metric
C15: 100nF; C_0805_2012Metric
C17, C18, C19, C20, C21, C22, C23, C24: 10nF X7R DNP; C_0805_2012Metric
C25, C26, C27, C28, C29, C30, C31, C32, C33, C34, C35, C36, C37, C38, C39, C40, C41, C42, C43, C44, C45, C46, C47, C48, C49, C50, C51, C52, C53, C54, C55, C56: 2.2uF X7R DNP; C_0805_2012Metric
D1, D3, D5, D7, D9, D11, D13, D15, D16, D18, D19, D20, D21, D22, D23, D24, D25, D26, D27, D28, D29, D30, D31, D32, D33, D34, D35, D36, D37, D38, D39, D40, D41, D42, D43, D44, D45, D46, D47, D48, D49, D50, D51, D52, D53, D54, D55, D56, D57, D58, D59, D60, D61, D62, D63, D64, D65, D66, D67, D68, D69, D70, D71, D72, D73, D74, D75, D76, D77, D78, D79, D80, D81, D82, D83, D84, D85, D86, D87, D88, D89, D90, D91, D92, D93, D94, D95, D96, D97: 1N4148; D_SOD-323
D2, D4, D6, D8, D10, D12, D14: MOV DNP; D_SMA
D17: SS34; D_SMA
F1: 1206L020YR 200mA; Fuse_1206_3216Metric
J1: J_PI; IDC-Header_2x10_P2.54mm_Vertical
J2: J_PWR 5V; TerminalBlock_Phoenix_MKDS-1,5-3-5.08_1x03_P5.08mm_Horizont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
J3: J_FAST_IN; PhoenixContact_MCV_1,5_10-G-3.5_1x10_P3.50mm_Vertical_D1.4
J4: J_SLOW_IN_A; PhoenixContact_MCV_1,5_14-G-3.5_1x14_P3.50mm_Vertical_D1.4
J5: J_SLOW_IN_B; PhoenixContact_MCV_1,5_12-G-3.5_1x12_P3.50mm_Vertical_D1.4
J6: J_MOTION_S 5.08mm; TerminalBlock_Phoenix_MKDS-1,5-2-5.08_1x02_P5.08mm_Horizont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
J7: J_MOTION_T 5.08mm; TerminalBlock_Phoenix_MKDS-1,5-2-5.08_1x02_P5.08mm_Horizont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
J8: J_MOTION_SP 5.08mm; TerminalBlock_Phoenix_MKDS-1,5-2-5.08_1x02_P5.08mm_Horizont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
J9: J_MOTION_BE 5.08mm; TerminalBlock_Phoenix_MKDS-1,5-2-5.08_1x02_P5.08mm_Horizont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
J10: J_MOTION_M 5.08mm; TerminalBlock_Phoenix_MKDS-1,5-2-5.08_1x02_P5.08mm_Horizont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
J11: J_MOTION_M2 5.08mm; TerminalBlock_Phoenix_MKDS-1,5-2-5.08_1x02_P5.08mm_Horizont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
J12: J_MOTION_M1 5.08mm; TerminalBlock_Phoenix_MKDS-1,5-2-5.08_1x02_P5.08mm_Horizont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
J13: J_LAMP_LED; PhoenixContact_MCV_1,5_6-G-3.5_1x06_P3.50mm_Vertical_D1.4
J14: J_SAFETY; PhoenixContact_MCV_1,5_4-G-3.5_1x04_P3.50mm_Vertical_D1.4
J15: J_SLOW_IN_C; PhoenixContact_MCV_1,5_10-G-3.5_1x10_P3.50mm_Vertical_D1.4
J16: J_EXT_I2C; PhoenixContact_MCV_1,5_6-G-3.5_1x06_P3.50mm_Vertical_D1.4
JP1: 3V3 LINK OPEN DNP; SolderJumper-2_P1.3mm_Open_RoundedPad1.0x1.5mm
K1: G5LE S; Relay_SPDT_Omron-G5LE-1
K2: G5LE T; Relay_SPDT_Omron-G5LE-1
K3: G5LE SP; Relay_SPDT_Omron-G5LE-1
K4: G5LE BE; Relay_SPDT_Omron-G5LE-1
K5: G5LE M; Relay_SPDT_Omron-G5LE-1
K6: G5LE M2; Relay_SPDT_Omron-G5LE-1
K7: G5LE M1 DNP; Relay_SPDT_Omron-G5LE-1
MK1, MK2, MK3, MK4: M3; MountingHole_3.2mm_M3
Q1: MMBT3904 S; SOT-23
Q2: MMBT3904 T; SOT-23
Q3: MMBT3904 SP; SOT-23
Q4: MMBT3904 BE; SOT-23
Q5: MMBT3904 M; SOT-23
Q6: MMBT3904 M2; SOT-23
Q7: MMBT3904 M1; SOT-23
Q8: 2N7002 LED L_FIRST; SOT-23
Q9: 2N7002 LED L_SECOND; SOT-23
Q10: 2N7002 LED L_STRIKE; SOT-23
Q11: 2N7002 LED L_FOUL; SOT-23
Q12: AO3400A kick; SOT-23
Q13: AO3400A wdog; SOT-23
Q14: AO3401A rail pass; SOT-23
Q15: MMBT3904 AND ARM; SOT-23
Q16: MMBT3904 AND RP_OK; SOT-23
Q17: 2N7002LT1G TAP 555; SOT-23
Q18: 2N7002LT1G TAP KICK; SOT-23
Q19: 2N7002LT1G TAP ARM; SOT-23
Q20: 2N7002LT1G TAP RPOK; SOT-23
R1, R2, R142, R143: 4.7k; R_0805_2012Metric
R3, R5, R7, R9, R11, R13, R15, R17, R19, R21, R23, R25, R27, R29, R31, R33, R35, R37, R39, R41, R43, R45, R47, R49, R51, R53, R55, R57, R59, R61, R63, R65, R67, R69, R71, R73, R75, R77, R79, R81, R122, R123: 2k2; R_0805_2012Metric
R4, R6, R8, R10, R12, R14, R16, R18, R20, R22, R24, R26, R28, R30, R32, R34, R36, R38, R40, R42, R44, R46, R48, R50, R52, R54, R56, R58, R60, R62, R64, R66, R68, R70, R72, R74, R76, R78, R80, R82: 47k; R_0805_2012Metric
R83, R86, R89, R92, R95, R98, R101, R104, R107, R110, R113, R118, R120: 1k; R_0805_2012Metric
R84, R87, R90, R93, R96, R99, R102, R105, R108, R111, R114, R116, R124, R126, R128: 100k; R_0805_2012Metric
R85, R88, R91, R94, R97, R100, R103: 100R DNP; R_0805_2012Metric
R106, R109, R112, R115: 330R; R_0805_2012Metric
R117, R119, R121, R125, R127, R129, R130, R132, R134, R137, R140, R144, R145: 10k; R_0805_2012Metric
R131, R133, R136, R139: 1M; R_0805_2012Metric
R135, R138, R141: 10M; R_0805_2012Metric
TP1: VCC_5V; TestPoint_Pad_1.5x1.5mm
TP2: GND; TestPoint_Pad_1.5x1.5mm
TP3: VCC_3V3; TestPoint_Pad_1.5x1.5mm
TP4: FIELD_WET_V; TestPoint_Pad_1.5x1.5mm
TP5: FIELD_GND; TestPoint_Pad_1.5x1.5mm
TP6: I2C_SDA; TestPoint_Pad_1.5x1.5mm
TP7: I2C_SCL; TestPoint_Pad_1.5x1.5mm
TP8: WDOG_KICK; TestPoint_Pad_1.5x1.5mm
TP9: WDOG_TIMING_NODE; TestPoint_Pad_1.5x1.5mm
TP10: NE555_TRIG; TestPoint_Pad_1.5x1.5mm
TP11: NE555_OUT; TestPoint_Pad_1.5x1.5mm
TP12: WDOG_OK_PULLDOWN; TestPoint_Pad_1.5x1.5mm
TP13: ARM_PERMIT; TestPoint_Pad_1.5x1.5mm
TP14: RP2040_OK; TestPoint_Pad_1.5x1.5mm
TP15: SAFE_STOP_RETURN; TestPoint_Pad_1.5x1.5mm
TP16: RELAY_ENABLE_RAIL; TestPoint_Pad_1.5x1.5mm
TP17: TAP_GATE_555; TestPoint_Pad_1.0x1.0mm
TP18: TAP_NE555_OUT; TestPoint_Pad_1.0x1.0mm
TP19: TAP_GATE_KICK; TestPoint_Pad_1.0x1.0mm
TP20: TAP_WDOG_KICK; TestPoint_Pad_1.0x1.0mm
TP21: TAP_GATE_ARM; TestPoint_Pad_1.0x1.0mm
TP22: TAP_ARM_PERMIT; TestPoint_Pad_1.0x1.0mm
TP23: TAP_GATE_RPOK; TestPoint_Pad_1.0x1.0mm
TP24: TAP_RP2040_OK; TestPoint_Pad_1.0x1.0mm
U1: MCP23017 MCP_IN_A; SOIC-28W_7.5x17.9mm_P1.27mm
U2: MCP23017 MCP_IN_B; SOIC-28W_7.5x17.9mm_P1.27mm
U3: MCP23017 MCP_OUT_A; SOIC-28W_7.5x17.9mm_P1.27mm
U4: PC817 SA; DIP-4_W7.62mm
U5: PC817 SB; DIP-4_W7.62mm
U6: PC817 SC; DIP-4_W7.62mm
U7: PC817 TA1; DIP-4_W7.62mm
U8: PC817 TA2; DIP-4_W7.62mm
U9: PC817 TB; DIP-4_W7.62mm
U10: PC817 DIELL_L; DIP-4_W7.62mm
U11: PC817 DIELL_R; DIP-4_W7.62mm
U12: PC817 GS1; DIP-4_W7.62mm
U13: PC817 GS2; DIP-4_W7.62mm
U14: PC817 GS3; DIP-4_W7.62mm
U15: PC817 GS4; DIP-4_W7.62mm
U16: PC817 GS5; DIP-4_W7.62mm
U17: PC817 GS6; DIP-4_W7.62mm
U18: PC817 GS7; DIP-4_W7.62mm
U19: PC817 GS8; DIP-4_W7.62mm
U20: PC817 GS9; DIP-4_W7.62mm
U21: PC817 GS10; DIP-4_W7.62mm
U22: PC817 GP; DIP-4_W7.62mm
U23: PC817 OS; DIP-4_W7.62mm
U24: PC817 BS; DIP-4_W7.62mm
U25: PC817 PBZ; DIP-4_W7.62mm
U26: PC817 PBC; DIP-4_W7.62mm
U27: PC817 FOUL; DIP-4_W7.62mm
U28: PC817 TENTH; DIP-4_W7.62mm
U29: PC817 MAN_T; DIP-4_W7.62mm
U30: PC817 MAN_S; DIP-4_W7.62mm
U31: PC817 MAN_SWS; DIP-4_W7.62mm
U32: PC817 MAN_SWSR; DIP-4_W7.62mm
U33: PC817 AUX1; DIP-4_W7.62mm
U34: PC817 AUX2; DIP-4_W7.62mm
U35: PC817 AUX3; DIP-4_W7.62mm
U36: PC817 AUX4; DIP-4_W7.62mm
U37: PC817 AUX5; DIP-4_W7.62mm
U38: PC817 AUX6; DIP-4_W7.62mm
U39: PC817 AUX7; DIP-4_W7.62mm
U40: PC817 AUX8; DIP-4_W7.62mm
U41: PC817 AUX9; DIP-4_W7.62mm
U42: PC817 AUX10; DIP-4_W7.62mm
U43: PC817 AUX11; DIP-4_W7.62mm
U44: NE555; SOIC-8_3.9x4.9mm_P1.27mm
U45: TMA-0505S; Converter_DCDC_TRACO_TMA-05xxS_12xxS_Single_THT
U46: TCA4307DGKR; VSSOP-8_3x3mm_P0.65mm
U47: SRV05-4; SOT-23-6

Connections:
ADC_VCC5_SENSE: A1.31, C15.1, R129.2, R130.1
AND_MID_ARM_RP: Q15.2, Q16.3
ARM_PERMIT: J1.8, R125.1, R136.1, TP13.1
BASE_AND_ARM: Q15.1, R125.2, R126.1
BASE_AND_RP_OK: Q16.1, R127.2, R128.1
BASE_BE: Q4.1, R92.2
BASE_M: Q5.1, R95.2
BASE_M1: Q7.1, R101.2
BASE_M2: Q6.1, R98.2
BASE_S: Q1.1, R83.2
BASE_SP: Q3.1, R89.2
BASE_T: Q2.1, R86.2
COIL_LO_BE: D7.2, K4.5, Q4.3
COIL_LO_M: D9.2, K5.5, Q5.3
COIL_LO_M1: D13.2, K7.5, Q7.3
COIL_LO_M2: D11.2, K6.5, Q6.3
COIL_LO_S: D1.2, K1.5, Q1.3
COIL_LO_SP: D5.2, K3.5, Q3.3
COIL_LO_T: D3.2, K2.5, Q2.3
DRV_BE: R92.1, R93.1, U3.24
DRV_L_FIRST: R104.1, U3.28
DRV_L_FOUL: R113.1, U3.3
DRV_L_SECOND: R107.1, U3.1
DRV_L_STRIKE: R110.1, U3.2
DRV_M: R95.1, R96.1, U3.25
DRV_M1: R101.1, R102.1, U3.27
DRV_M2: R98.1, R99.1, U3.26
DRV_S: R83.1, R84.1, U3.21
DRV_SP: R89.1, R90.1, U3.23
DRV_T: R86.1, R87.1, U3.22
FAST_DIELL_L: A1.16, C23.1, R16.2, U10.4
FAST_DIELL_R: A1.17, C24.1, R18.2, U11.4
FAST_SA: A1.9, C17.1, R4.2, U4.4
FAST_SB: A1.10, C18.1, R6.2, U5.4
FAST_SC: A1.11, C19.1, R8.2, U6.4
FAST_TA1: A1.12, C20.1, R10.2, U7.4
FAST_TA2: A1.14, C21.1, R12.2, U8.4
FAST_TB: A1.15, C22.1, R14.2, U9.4
FIELD_FAST_DIELL_L: D31.2, J3.7, U10.2
FIELD_FAST_DIELL_R: D33.2, J3.8, U11.2
FIELD_FAST_SA: D19.2, J3.1, U4.2
FIELD_FAST_SB: D21.2, J3.2, U5.2
FIELD_FAST_SC: D23.2, J3.3, U6.2
FIELD_FAST_TA1: D25.2, J3.4, U7.2
FIELD_FAST_TA2: D27.2, J3.5, U8.2
FIELD_FAST_TB: D29.2, J3.6, U9.2
FIELD_GND: J3.9, J3.10, J4.14, J5.12, J15.9, J15.10, R122.2, R123.2, TP5.1, U45.4
FIELD_LED_AUX1: D76.1, D77.1, U33.1
FIELD_LED_AUX2: D78.1, D79.1, U34.1
FIELD_LED_AUX3: D80.1, D81.1, U35.1
FIELD_LED_AUX4: D82.1, D83.1, U36.1
FIELD_LED_AUX5: D84.1, D85.1, U37.1
FIELD_LED_AUX6: D86.1, D87.1, U38.1
FIELD_LED_AUX7: D88.1, D89.1, U39.1
FIELD_LED_AUX8: D90.1, D91.1, U40.1
FIELD_LED_AUX9: D92.1, D93.1, U41.1
FIELD_LED_AUX10: D94.1, D95.1, U42.1
FIELD_LED_AUX11: D96.1, D97.1, U43.1
FIELD_LED_BS: D58.1, D59.1, U24.1
FIELD_LED_DIELL_L: D30.1, D31.1, U10.1
FIELD_LED_DIELL_R: D32.1, D33.1, U11.1
FIELD_LED_FOUL: D64.1, D65.1, U27.1
FIELD_LED_GP: D54.1, D55.1, U22.1
FIELD_LED_GS1: D34.1, D35.1, U12.1
FIELD_LED_GS2: D36.1, D37.1, U13.1
FIELD_LED_GS3: D38.1, D39.1, U14.1
FIELD_LED_GS4: D40.1, D41.1, U15.1
FIELD_LED_GS5: D42.1, D43.1, U16.1
FIELD_LED_GS6: D44.1, D45.1, U17.1
FIELD_LED_GS7: D46.1, D47.1, U18.1
FIELD_LED_GS8: D48.1, D49.1, U19.1
FIELD_LED_GS9: D50.1, D51.1, U20.1
FIELD_LED_GS10: D52.1, D53.1, U21.1
FIELD_LED_MAN_S: D70.1, D71.1, U30.1
FIELD_LED_MAN_SWS: D72.1, D73.1, U31.1
FIELD_LED_MAN_SWSR: D74.1, D75.1, U32.1
FIELD_LED_MAN_T: D68.1, D69.1, U29.1
FIELD_LED_OS: D56.1, D57.1, U23.1
FIELD_LED_PBC: D62.1, D63.1, U26.1
FIELD_LED_PBZ: D60.1, D61.1, U25.1
FIELD_LED_SA: D18.1, D19.1, U4.1
FIELD_LED_SB: D20.1, D21.1, U5.1
FIELD_LED_SC: D22.1, D23.1, U6.1
FIELD_LED_TA1: D24.1, D25.1, U7.1
FIELD_LED_TA2: D26.1, D27.1, U8.1
FIELD_LED_TB: D28.1, D29.1, U9.1
FIELD_LED_TENTH: D66.1, D67.1, U28.1
FIELD_RIN_AUX1: D76.2, R61.2
FIELD_RIN_AUX2: D78.2, R63.2
FIELD_RIN_AUX3: D80.2, R65.2
FIELD_RIN_AUX4: D82.2, R67.2
FIELD_RIN_AUX5: D84.2, R69.2
FIELD_RIN_AUX6: D86.2, R71.2
FIELD_RIN_AUX7: D88.2, R73.2
FIELD_RIN_AUX8: D90.2, R75.2
FIELD_RIN_AUX9: D92.2, R77.2
FIELD_RIN_AUX10: D94.2, R79.2
FIELD_RIN_AUX11: D96.2, R81.2
FIELD_RIN_BS: D58.2, R43.2
FIELD_RIN_DIELL_L: D30.2, R15.2
FIELD_RIN_DIELL_R: D32.2, R17.2
FIELD_RIN_FOUL: D64.2, R49.2
FIELD_RIN_GP: D54.2, R39.2
FIELD_RIN_GS1: D34.2, R19.2
FIELD_RIN_GS2: D36.2, R21.2
FIELD_RIN_GS3: D38.2, R23.2
FIELD_RIN_GS4: D40.2, R25.2
FIELD_RIN_GS5: D42.2, R27.2
FIELD_RIN_GS6: D44.2, R29.2
FIELD_RIN_GS7: D46.2, R31.2
FIELD_RIN_GS8: D48.2, R33.2
FIELD_RIN_GS9: D50.2, R35.2
FIELD_RIN_GS10: D52.2, R37.2
FIELD_RIN_MAN_S: D70.2, R55.2
FIELD_RIN_MAN_SWS: D72.2, R57.2
FIELD_RIN_MAN_SWSR: D74.2, R59.2
FIELD_RIN_MAN_T: D68.2, R53.2
FIELD_RIN_OS: D56.2, R41.2
FIELD_RIN_PBC: D62.2, R47.2
FIELD_RIN_PBZ: D60.2, R45.2
FIELD_RIN_SA: D18.2, R3.2
FIELD_RIN_SB: D20.2, R5.2
FIELD_RIN_SC: D22.2, R7.2
FIELD_RIN_TA1: D24.2, R9.2
FIELD_RIN_TA2: D26.2, R11.2
FIELD_RIN_TB: D28.2, R13.2
FIELD_RIN_TENTH: D66.2, R51.2
FIELD_SLOW_AUX1: D77.2, J5.9, U33.2
FIELD_SLOW_AUX2: D79.2, J5.10, U34.2
FIELD_SLOW_AUX3: D81.2, J5.11, U35.2
FIELD_SLOW_AUX4: D83.2, J15.1, U36.2
FIELD_SLOW_AUX5: D85.2, J15.2, U37.2
FIELD_SLOW_AUX6: D87.2, J15.3, U38.2
FIELD_SLOW_AUX7: D89.2, J15.4, U39.2
FIELD_SLOW_AUX8: D91.2, J15.5, U40.2
FIELD_SLOW_AUX9: D93.2, J15.6, U41.2
FIELD_SLOW_AUX10: D95.2, J15.7, U42.2
FIELD_SLOW_AUX11: D97.2, J15.8, U43.2
FIELD_SLOW_BS: D59.2, J4.13, U24.2
FIELD_SLOW_FOUL: D65.2, J5.3, U27.2
FIELD_SLOW_GP: D55.2, J4.11, U22.2
FIELD_SLOW_GS1: D35.2, J4.1, U12.2
FIELD_SLOW_GS2: D37.2, J4.2, U13.2
FIELD_SLOW_GS3: D39.2, J4.3, U14.2
FIELD_SLOW_GS4: D41.2, J4.4, U15.2
FIELD_SLOW_GS5: D43.2, J4.5, U16.2
FIELD_SLOW_GS6: D45.2, J4.6, U17.2
FIELD_SLOW_GS7: D47.2, J4.7, U18.2
FIELD_SLOW_GS8: D49.2, J4.8, U19.2
FIELD_SLOW_GS9: D51.2, J4.9, U20.2
FIELD_SLOW_GS10: D53.2, J4.10, U21.2
FIELD_SLOW_MAN_S: D71.2, J5.6, U30.2
FIELD_SLOW_MAN_SWS: D73.2, J5.7, U31.2
FIELD_SLOW_MAN_SWSR: D75.2, J5.8, U32.2
FIELD_SLOW_MAN_T: D69.2, J5.5, U29.2
FIELD_SLOW_OS: D57.2, J4.12, U23.2
FIELD_SLOW_PBC: D63.2, J5.2, U26.2
FIELD_SLOW_PBZ: D61.2, J5.1, U25.2
FIELD_SLOW_TENTH: D67.2, J5.4, U28.2
FIELD_WET_V: R3.1, R5.1, R7.1, R9.1, R11.1, R13.1, R15.1, R17.1, R19.1, R21.1, R23.1, R25.1, R27.1, R29.1, R31.1, R33.1, R35.1, R37.1, R39.1, R41.1, R43.1, R45.1, R47.1, R49.1, R51.1, R53.1, R55.1, R57.1, R59.1, R61.1, R63.1, R65.1, R67.1, R69.1, R71.1, R73.1, R75.1, R77.1, R79.1, R81.1, R122.1, R123.1, TP4.1, U45.6
GND: A1.3, A1.8, A1.13, A1.18, A1.23, A1.28, A1.33, A1.38, C1.2, C2.2, C3.2, C11.2, C12.2, C13.2, C14.2, C15.2, C16.2, C17.2, C18.2, C19.2, C20.2, C21.2, C22.2, C23.2, C24.2, C25.2, C26.2, C27.2, C28.2, C29.2, C30.2, C31.2, C32.2, C33.2, C34.2, C35.2, C36.2, C37.2, C38.2, C39.2, C40.2, C41.2, C42.2, C43.2, C44.2, C45.2, C46.2, C47.2, C48.2, C49.2, C50.2, C51.2, C52.2, C53.2, C54.2, C55.2, C56.2, J1.2, J1.12, J2.2, J2.3, J13.2, J16.2, J16.6, Q1.2, Q2.2, Q3.2, Q4.2, Q5.2, Q6.2, Q7.2, Q8.2, Q9.2, Q10.2, Q11.2, Q12.2, Q13.2, Q17.2, Q18.2, Q19.2, Q20.2, R84.2, R87.2, R90.2, R93.2, R96.2, R99.2, R102.2, R105.2, R108.2, R111.2, R114.2, R119.2, R121.2, R126.2, R128.2, R130.2, R135.2, R138.2, R141.2, R145.1, TP2.1, U1.10, U1.15, U1.16, U1.17, U2.10, U2.16, U2.17, U3.10, U3.15, U3.17, U4.3, U5.3, U6.3, U7.3, U8.3, U9.3, U10.3, U11.3, U12.3, U13.3, U14.3, U15.3, U16.3, U17.3, U18.3, U19.3, U20.3, U21.3, U22.3, U23.3, U24.3, U25.3, U26.3, U27.3, U28.3, U29.3, U30.3, U31.3, U32.3, U33.3, U34.3, U35.3, U36.3, U37.3, U38.3, U39.3, U40.3, U41.3, U42.3, U43.3, U44.1, U45.2, U46.4, U47.2
I2C_SCL: J1.4, R2.2, TP7.1, U1.12, U2.12, U3.12, U46.3
I2C_SDA: J1.3, R1.2, TP6.1, U1.13, U2.13, U3.13, U46.6
J16_3V3: J16.5, JP1.2, U47.1
J16_5V: F1.2, J16.1, U47.4
J16_SCL: J16.4, R143.2, U46.2, U47.6
J16_SDA: J16.3, R142.2, U46.7, U47.3
LED_GATE_L_FIRST: Q8.1, R104.2, R105.1
LED_GATE_L_FOUL: Q11.1, R113.2, R114.1
LED_GATE_L_SECOND: Q9.1, R107.2, R108.1
LED_GATE_L_STRIKE: Q10.1, R110.2, R111.1
LED_L_FIRST_RETURN: J13.3, R106.1
LED_L_FOUL_RETURN: J13.6, R115.1
LED_L_SECOND_RETURN: J13.4, R109.1
LED_L_STRIKE_RETURN: J13.5, R112.1
LED_SINK_L_FIRST: Q8.3, R106.2
LED_SINK_L_FOUL: Q11.3, R115.2
LED_SINK_L_SECOND: Q9.3, R109.2
LED_SINK_L_STRIKE: Q10.3, R112.2
MCP_INT_A: J1.9, U1.20
MCP_INT_B: J1.10, U2.20
NE555_CTRL: C13.1, U44.5
NE555_OUT: R120.1, R131.1, TP11.1, U44.3
NE555_TRIG: D16.2, R117.2, TP10.1, U44.2
OUT_BE_A: D8.1, J9.2, K4.1, R94.1
OUT_BE_B: C7.2, D8.2, J9.1, K4.3
OUT_M1_A: D14.1, J12.2, K7.1, R103.1
OUT_M1_B: C10.2, D14.2, J12.1, K7.3
OUT_M2_A: D12.1, J11.2, K6.1, R100.1
OUT_M2_B: C9.2, D12.2, J11.1, K6.3
OUT_M_A: D10.1, J10.2, K5.1, R97.1
OUT_M_B: C8.2, D10.2, J10.1, K5.3
OUT_SP_A: D6.1, J8.2, K3.1, R91.1
OUT_SP_B: C6.2, D6.2, J8.1, K3.3
OUT_S_A: D2.1, J6.2, K1.1, R85.1
OUT_S_B: C4.2, D2.2, J6.1, K1.3
OUT_T_A: D4.1, J7.2, K2.1, R88.1
OUT_T_B: C5.2, D4.2, J7.1, K2.3
PI_UART_RX: A1.1, J1.6
PI_UART_TX: A1.2, J1.5
RAIL_GATE: Q14.1, Q15.3, R124.2
RELAY_ENABLE_RAIL: D1.1, D3.1, D5.1, D7.1, D9.1, D11.1, D13.1, K1.2, K2.2, K3.2, K4.2, K5.2, K6.2, K7.2, Q14.3, TP16.1
REV_ID0: A1.26, R144.2
REV_ID1: A1.27, R145.2
RP2040_OK: A1.4, J1.13, R127.1, R139.1, TP14.1
SAFE_STOP_RETURN: J14.4, Q14.2, R124.1, TP15.1
SAFE_TBSC_RETURN: J14.2, J14.3
SLOW_AUX1: C46.1, R62.2, U2.26, U33.4
SLOW_AUX2: C47.1, R64.2, U2.27, U34.4
SLOW_AUX3: C48.1, R66.2, U2.28, U35.4
SLOW_AUX4: C49.1, R68.2, U2.1, U36.4
SLOW_AUX5: C50.1, R70.2, U2.2, U37.4
SLOW_AUX6: C51.1, R72.2, U2.3, U38.4
SLOW_AUX7: C52.1, R74.2, U2.4, U39.4
SLOW_AUX8: C53.1, R76.2, U2.5, U40.4
SLOW_AUX9: C54.1, R78.2, U2.6, U41.4
SLOW_AUX10: C55.1, R80.2, U2.7, U42.4
SLOW_AUX11: C56.1, R82.2, U2.8, U43.4
SLOW_BS: C37.1, R44.2, U1.5, U24.4
SLOW_FOUL: C40.1, R50.2, U1.8, U27.4
SLOW_GP: C35.1, R40.2, U1.3, U22.4
SLOW_GS1: C25.1, R20.2, U1.21, U12.4
SLOW_GS2: C26.1, R22.2, U1.22, U13.4
SLOW_GS3: C27.1, R24.2, U1.23, U14.4
SLOW_GS4: C28.1, R26.2, U1.24, U15.4
SLOW_GS5: C29.1, R28.2, U1.25, U16.4
SLOW_GS6: C30.1, R30.2, U1.26, U17.4
SLOW_GS7: C31.1, R32.2, U1.27, U18.4
SLOW_GS8: C32.1, R34.2, U1.28, U19.4
SLOW_GS9: C33.1, R36.2, U1.1, U20.4
SLOW_GS10: C34.1, R38.2, U1.2, U21.4
SLOW_MAN_S: C43.1, R56.2, U2.23, U30.4
SLOW_MAN_SWS: C44.1, R58.2, U2.24, U31.4
SLOW_MAN_SWSR: C45.1, R60.2, U2.25, U32.4
SLOW_MAN_T: C42.1, R54.2, U2.22, U29.4
SLOW_OS: C36.1, R42.2, U1.4, U23.4
SLOW_PBC: C39.1, R48.2, U1.7, U26.4
SLOW_PBZ: C38.1, R46.2, U1.6, U25.4
SLOW_TENTH: C41.1, R52.2, U2.21, U28.4
SNUB_BE: C7.1, R94.2
SNUB_M: C8.1, R97.2
SNUB_M1: C10.1, R103.2
SNUB_M2: C9.1, R100.2
SNUB_S: C4.1, R85.2
SNUB_SP: C6.1, R91.2
SNUB_T: C5.1, R88.2
TAP_ARM_PERMIT: A1.24, Q19.3, R137.2, TP22.1
TAP_GATE_555: Q17.1, R131.2, TP17.1
TAP_GATE_ARM: Q19.1, R136.2, R138.1, TP21.1
TAP_GATE_KICK: Q18.1, R133.2, R135.1, TP19.1
TAP_GATE_RPOK: Q20.1, R139.2, R141.1, TP23.1
TAP_NE555_OUT: A1.21, Q17.3, R132.2, TP18.1
TAP_RP2040_OK: A1.25, Q20.3, R140.2, TP24.1
TAP_WDOG_KICK: A1.22, Q18.3, R134.2, TP20.1
VCC_3V3: A1.36, C1.1, C2.1, C3.1, C14.1, C16.1, J1.11, JP1.1, R1.1, R2.1, R4.1, R6.1, R8.1, R10.1, R12.1, R14.1, R16.1, R18.1, R20.1, R22.1, R24.1, R26.1, R28.1, R30.1, R32.1, R34.1, R36.1, R38.1, R40.1, R42.1, R44.1, R46.1, R48.1, R50.1, R52.1, R54.1, R56.1, R58.1, R60.1, R62.1, R64.1, R66.1, R68.1, R70.1, R72.1, R74.1, R76.1, R78.1, R80.1, R82.1, R132.1, R134.1, R137.1, R140.1, R142.1, R143.1, R144.1, TP3.1, U1.9, U1.18, U2.9, U2.15, U2.18, U3.9, U3.16, U3.18, U46.1, U46.8
VCC_5V: A1.39, C12.1, D17.1, F1.1, J1.1, J13.1, J14.1, R116.1, R117.1, R129.1, TP1.1, U44.4, U44.8, U45.1, U47.5
VCC_5V_RAW: D17.2, J2.1
WDOG_KICK: J1.7, R118.1, R133.1, TP8.1
WDOG_KICK_DRAIN: D15.1, D16.1, Q12.3
WDOG_KICK_GATE: Q12.1, R118.2, R119.1
WDOG_OK_GATE: Q13.1, R120.2, R121.1
WDOG_OK_PULLDOWN: Q13.3, Q16.2, TP12.1
WDOG_TIMING_NODE: C11.1, D15.2, R116.2, TP9.1, U44.6, U44.7

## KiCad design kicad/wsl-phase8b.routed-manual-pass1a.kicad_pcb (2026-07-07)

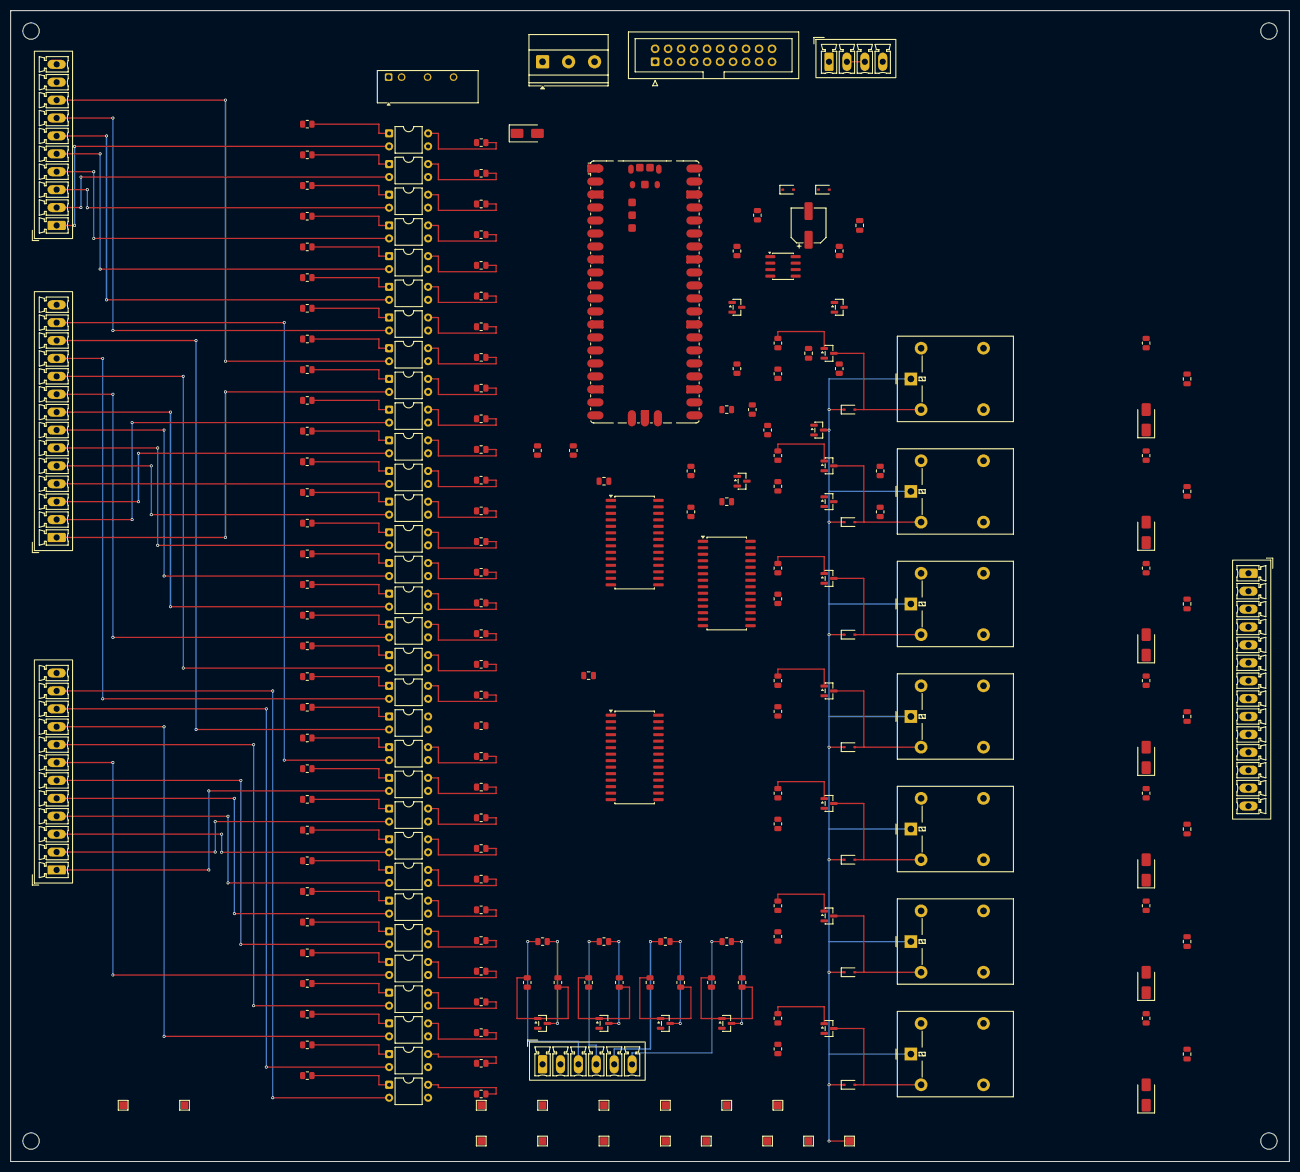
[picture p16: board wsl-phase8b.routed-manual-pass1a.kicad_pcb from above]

Board: 4 copper layers, 250.0 x 225.0 mm, 230 parts (0 on the bottom side), 184 nets.

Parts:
A1: RP2040 Pico; RaspberryPi_Pico_SMD
C1, C2, C3, C12: 0.1uF; C_0805_2012Metric
C4, C5, C6, C7, C8, C9, C10: 10nF X2 DNP; C_0805_2012Metric
C11: 100uF/16V; CP_Elec_6.3x5.4
C13: 10nF; C_0805_2012Metric
C14: 10uF; C_0805_2012Metric
D1, D3, D5, D7, D9, D11, D13, D15, D16: 1N4148; D_SOD-323
D2, D4, D6, D8, D10, D12, D14: MOV DNP; D_SMA
D17: SS14; D_SMA
J1: J_PI; IDC-Header_2x10_P2.54mm_Vertical
J2: J_PWR 5V; TerminalBlock_Phoenix_MKDS-1,5-3-5.08_1x03_P5.08mm_Horizont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
J3: J_FAST_IN; PhoenixContact_MCV_1,5_10-G-3.5_1x10_P3.50mm_Vertical
J4: J_SLOW_IN_A; PhoenixContact_MCV_1,5_14-G-3.5_1x14_P3.50mm_Vertical
J5: J_SLOW_IN_B; PhoenixContact_MCV_1,5_12-G-3.5_1x12_P3.50mm_Vertical
J6: J_MOTION_OUT; PhoenixContact_MCV_1,5_14-G-3.5_1x14_P3.50mm_Vertical
J7: J_LAMP_LED; PhoenixContact_MCV_1,5_6-G-3.5_1x06_P3.50mm_Vertical
J8: J_SAFETY; PhoenixContact_MCV_1,5_4-G-3.5_1x04_P3.50mm_Vertical
K1: G5LE S; Relay_SPDT_Omron-G5LE-1
K2: G5LE T; Relay_SPDT_Omron-G5LE-1
K3: G5LE SP; Relay_SPDT_Omron-G5LE-1
K4: G5LE BE; Relay_SPDT_Omron-G5LE-1
K5: G5LE M; Relay_SPDT_Omron-G5LE-1
K6: G5LE M2; Relay_SPDT_Omron-G5LE-1
K7: G5LE M1 DNP; Relay_SPDT_Omron-G5LE-1
MK1, MK2, MK3, MK4: M3; MountingHole_3.2mm_M3
Q1: MMBT3904 S; SOT-23
Q2: MMBT3904 T; SOT-23
Q3: MMBT3904 SP; SOT-23
Q4: MMBT3904 BE; SOT-23
Q5: MMBT3904 M; SOT-23
Q6: MMBT3904 M2; SOT-23
Q7: MMBT3904 M1; SOT-23
Q8: 2N7002 LED L_FIRST; SOT-23
Q9: 2N7002 LED L_SECOND; SOT-23
Q10: 2N7002 LED L_STRIKE; SOT-23
Q11: 2N7002 LED L_FOUL; SOT-23
Q12: AO3400A kick; SOT-23
Q13: AO3400A wdog; SOT-23
Q14: AO3401A rail pass; SOT-23
Q15: AND ARM; SOT-23
Q16: AND RP_OK; SOT-23
R1, R2: 4.7k; R_0805_2012Metric
R3, R5, R7, R9, R11, R13, R15, R17, R19, R21, R23, R25, R27, R29, R31, R33, R35, R37, R39, R41, R43, R45, R47, R49, R51, R53, R55, R57, R59, R61, R63, R65: 2k2; R_0805_2012Metric
R4, R6, R8, R10, R12, R14, R16, R18, R20, R22, R24, R26, R28, R30, R32, R34, R36, R38, R40, R42, R44, R46, R48, R50, R52, R54, R56, R58, R60, R62, R64, R66, R101, R103, R105, R107, R109: 10k; R_0805_2012Metric
R67, R70, R73, R76, R79, R82, R85, R88, R91, R94, R97, R102, R104: 1k; R_0805_2012Metric
R68, R71, R74, R77, R80, R83, R86, R89, R92, R95, R98, R100, R106, R108, R110: 100k; R_0805_2012Metric
R69, R72, R75, R78, R81, R84, R87: 100R DNP; R_0805_2012Metric
R90, R93, R96, R99: 330R TBD; R_0805_2012Metric
TP1: VCC_5V; TestPoint_Pad_1.5x1.5mm
TP2: GND; TestPoint_Pad_1.5x1.5mm
TP3: VCC_3V3; TestPoint_Pad_1.5x1.5mm
TP4: FIELD_WET_V; TestPoint_Pad_1.5x1.5mm
TP5: FIELD_GND; TestPoint_Pad_1.5x1.5mm
TP6: I2C_SDA; TestPoint_Pad_1.5x1.5mm
TP7: I2C_SCL; TestPoint_Pad_1.5x1.5mm
TP8: WDOG_KICK; TestPoint_Pad_1.5x1.5mm
TP9: WDOG_TIMING_NODE; TestPoint_Pad_1.5x1.5mm
TP10: NE555_TRIG; TestPoint_Pad_1.5x1.5mm
TP11: NE555_OUT; TestPoint_Pad_1.5x1.5mm
TP12: WDOG_OK_PULLDOWN; TestPoint_Pad_1.5x1.5mm
TP13: ARM_PERMIT; TestPoint_Pad_1.5x1.5mm
TP14: RP2040_OK; TestPoint_Pad_1.5x1.5mm
TP15: SAFE_STOP_RETURN; TestPoint_Pad_1.5x1.5mm
TP16: RELAY_ENABLE_RAIL; TestPoint_Pad_1.5x1.5mm
U1: MCP23017 MCP_IN_A; SOIC-28W_7.5x17.9mm_P1.27mm
U2: MCP23017 MCP_IN_B; SOIC-28W_7.5x17.9mm_P1.27mm
U3: MCP23017 MCP_OUT_A; SOIC-28W_7.5x17.9mm_P1.27mm
U4: PC817 SA; DIP-4_W7.62mm
U5: PC817 SB; DIP-4_W7.62mm
U6: PC817 SC; DIP-4_W7.62mm
U7: PC817 TA1; DIP-4_W7.62mm
U8: PC817 TA2; DIP-4_W7.62mm
U9: PC817 TB; DIP-4_W7.62mm
U10: PC817 DIELL_L; DIP-4_W7.62mm
U11: PC817 DIELL_R; DIP-4_W7.62mm
U12: PC817 GS1; DIP-4_W7.62mm
U13: PC817 GS2; DIP-4_W7.62mm
U14: PC817 GS3; DIP-4_W7.62mm
U15: PC817 GS4; DIP-4_W7.62mm
U16: PC817 GS5; DIP-4_W7.62mm
U17: PC817 GS6; DIP-4_W7.62mm
U18: PC817 GS7; DIP-4_W7.62mm
U19: PC817 GS8; DIP-4_W7.62mm
U20: PC817 GS9; DIP-4_W7.62mm
U21: PC817 GS10; DIP-4_W7.62mm
U22: PC817 GP; DIP-4_W7.62mm
U23: PC817 OS; DIP-4_W7.62mm
U24: PC817 BS; DIP-4_W7.62mm
U25: PC817 PBZ; DIP-4_W7.62mm
U26: PC817 PBC; DIP-4_W7.62mm
U27: PC817 FOUL; DIP-4_W7.62mm
U28: PC817 TENTH; DIP-4_W7.62mm
U29: PC817 MAN_T; DIP-4_W7.62mm
U30: PC817 MAN_S; DIP-4_W7.62mm
U31: PC817 MAN_SWS; DIP-4_W7.62mm
U32: PC817 MAN_SWSR; DIP-4_W7.62mm
U33: PC817 AUX1; DIP-4_W7.62mm
U34: PC817 AUX2; DIP-4_W7.62mm
U35: PC817 AUX3; DIP-4_W7.62mm
U36: NE555; SOIC-8_3.9x4.9mm_P1.27mm
U37: TMA-0505S; Converter_DCDC_TRACO_TMA-05xxS_12xxS_Single_THT

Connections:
AND_MID_ARM_RP: Q15.2, Q16.3
ARM_PERMIT: J1.8, R107.1, TP13.1
BASE_AND_ARM: Q15.1, R107.2, R108.1
BASE_AND_RP_OK: Q16.1, R109.2, R110.1
BASE_BE: Q4.1, R76.2
BASE_M: Q5.1, R79.2
BASE_M1: Q7.1, R85.2
BASE_M2: Q6.1, R82.2
BASE_S: Q1.1, R67.2
BASE_SP: Q3.1, R73.2
BASE_T: Q2.1, R70.2
COIL_LO_BE: D7.2, K4.2, Q4.3
COIL_LO_M: D9.2, K5.2, Q5.3
COIL_LO_M1: D13.2, K7.2, Q7.3
COIL_LO_M2: D11.2, K6.2, Q6.3
COIL_LO_S: D1.2, K1.2, Q1.3
COIL_LO_SP: D5.2, K3.2, Q3.3
COIL_LO_T: D3.2, K2.2, Q2.3
DRV_BE: R76.1, R77.1, U3.24
DRV_L_FIRST: R88.1, U3.28
DRV_L_FOUL: R97.1, U3.3
DRV_L_SECOND: R91.1, U3.1
DRV_L_STRIKE: R94.1, U3.2
DRV_M: R79.1, R80.1, U3.25
DRV_M1: R85.1, R86.1, U3.27
DRV_M2: R82.1, R83.1, U3.26
DRV_S: R67.1, R68.1, U3.21
DRV_SP: R73.1, R74.1, U3.23
DRV_T: R70.1, R71.1, U3.22
FAST_DIELL_L: A1.16, R16.2, U10.4
FAST_DIELL_R: A1.17, R18.2, U11.4
FAST_SA: A1.9, R4.2, U4.4
FAST_SB: A1.10, R6.2, U5.4
FAST_SC: A1.11, R8.2, U6.4
FAST_TA1: A1.12, R10.2, U7.4
FAST_TA2: A1.14, R12.2, U8.4
FAST_TB: A1.15, R14.2, U9.4
FIELD_FAST_DIELL_L: J3.7, U10.2
FIELD_FAST_DIELL_R: J3.8, U11.2
FIELD_FAST_SA: J3.1, U4.2
FIELD_FAST_SB: J3.2, U5.2
FIELD_FAST_SC: J3.3, U6.2
FIELD_FAST_TA1: J3.4, U7.2
FIELD_FAST_TA2: J3.5, U8.2
FIELD_FAST_TB: J3.6, U9.2
FIELD_GND: J3.9, J3.10, J4.14, J5.12, TP5.1, U37.4
FIELD_LED_AUX1: R61.2, U33.1
FIELD_LED_AUX2: R63.2, U34.1
FIELD_LED_AUX3: R65.2, U35.1
FIELD_LED_BS: R43.2, U24.1
FIELD_LED_DIELL_L: R15.2, U10.1
FIELD_LED_DIELL_R: R17.2, U11.1
FIELD_LED_FOUL: R49.2, U27.1
FIELD_LED_GP: R39.2, U22.1
FIELD_LED_GS1: R19.2, U12.1
FIELD_LED_GS2: R21.2, U13.1
FIELD_LED_GS3: R23.2, U14.1
FIELD_LED_GS4: R25.2, U15.1
FIELD_LED_GS5: R27.2, U16.1
FIELD_LED_GS6: R29.2, U17.1
FIELD_LED_GS7: R31.2, U18.1
FIELD_LED_GS8: R33.2, U19.1
FIELD_LED_GS9: R35.2, U20.1
FIELD_LED_GS10: R37.2, U21.1
FIELD_LED_MAN_S: R55.2, U30.1
FIELD_LED_MAN_SWS: R57.2, U31.1
FIELD_LED_MAN_SWSR: R59.2, U32.1
FIELD_LED_MAN_T: R53.2, U29.1
FIELD_LED_OS: R41.2, U23.1
FIELD_LED_PBC: R47.2, U26.1
FIELD_LED_PBZ: R45.2, U25.1
FIELD_LED_SA: R3.2, U4.1
FIELD_LED_SB: R5.2, U5.1
FIELD_LED_SC: R7.2, U6.1
FIELD_LED_TA1: R9.2, U7.1
FIELD_LED_TA2: R11.2, U8.1
FIELD_LED_TB: R13.2, U9.1
FIELD_LED_TENTH: R51.2, U28.1
FIELD_SLOW_AUX1: J5.9, U33.2
FIELD_SLOW_AUX2: J5.10, U34.2
FIELD_SLOW_AUX3: J5.11, U35.2
FIELD_SLOW_BS: J4.13, U24.2
FIELD_SLOW_FOUL: J5.3, U27.2
FIELD_SLOW_GP: J4.11, U22.2
FIELD_SLOW_GS1: J4.1, U12.2
FIELD_SLOW_GS2: J4.2, U13.2
FIELD_SLOW_GS3: J4.3, U14.2
FIELD_SLOW_GS4: J4.4, U15.2
FIELD_SLOW_GS5: J4.5, U16.2
FIELD_SLOW_GS6: J4.6, U17.2
FIELD_SLOW_GS7: J4.7, U18.2
FIELD_SLOW_GS8: J4.8, U19.2
FIELD_SLOW_GS9: J4.9, U20.2
FIELD_SLOW_GS10: J4.10, U21.2
FIELD_SLOW_MAN_S: J5.6, U30.2
FIELD_SLOW_MAN_SWS: J5.7, U31.2
FIELD_SLOW_MAN_SWSR: J5.8, U32.2
FIELD_SLOW_MAN_T: J5.5, U29.2
FIELD_SLOW_OS: J4.12, U23.2
FIELD_SLOW_PBC: J5.2, U26.2
FIELD_SLOW_PBZ: J5.1, U25.2
FIELD_SLOW_TENTH: J5.4, U28.2
FIELD_WET_V: R3.1, R5.1, R7.1, R9.1, R11.1, R13.1, R15.1, R17.1, R19.1, R21.1, R23.1, R25.1, R27.1, R29.1, R31.1, R33.1, R35.1, R37.1, R39.1, R41.1, R43.1, R45.1, R47.1, R49.1, R51.1, R53.1, R55.1, R57.1, R59.1, R61.1, R63.1, R65.1, TP4.1, U37.6
GND: A1.3, A1.8, A1.13, A1.18, A1.23, A1.28, A1.33, A1.38, C1.2, C2.2, C3.2, C11.2, C12.2, C13.2, C14.2, J1.2, J1.12, J2.2, J2.3, J7.2, Q1.2, Q2.2, Q3.2, Q4.2, Q5.2, Q6.2, Q7.2, Q8.2, Q9.2, Q10.2, Q11.2, Q12.2, Q13.2, R68.2, R71.2, R74.2, R77.2, R80.2, R83.2, R86.2, R89.2, R92.2, R95.2, R98.2, R103.2, R105.2, R108.2, R110.2, TP2.1, U1.10, U1.15, U1.16, U1.17, U2.10, U2.16, U2.17, U3.10, U3.15, U3.17, U4.3, U5.3, U6.3, U7.3, U8.3, U9.3, U10.3, U11.3, U12.3, U13.3, U14.3, U15.3, U16.3, U17.3, U18.3, U19.3, U20.3, U21.3, U22.3, U23.3, U24.3, U25.3, U26.3, U27.3, U28.3, U29.3, U30.3, U31.3, U32.3, U33.3, U34.3, U35.3, U36.1, U37.2
I2C_SCL: J1.4, R2.2, TP7.1, U1.12, U2.12, U3.12
I2C_SDA: J1.3, R1.2, TP6.1, U1.13, U2.13, U3.13
LED_GATE_L_FIRST: Q8.1, R88.2, R89.1
LED_GATE_L_FOUL: Q11.1, R97.2, R98.1
LED_GATE_L_SECOND: Q9.1, R91.2, R92.1
LED_GATE_L_STRIKE: Q10.1, R94.2, R95.1
LED_L_FIRST_RETURN: J7.3, R90.1
LED_L_FOUL_RETURN: J7.6, R99.1
LED_L_SECOND_RETURN: J7.4, R93.1
LED_L_STRIKE_RETURN: J7.5, R96.1
LED_SINK_L_FIRST: Q8.3, R90.2
LED_SINK_L_FOUL: Q11.3, R99.2
LED_SINK_L_SECOND: Q9.3, R93.2
LED_SINK_L_STRIKE: Q10.3, R96.2
MCP_INT_A: J1.9, U1.20
MCP_INT_B: J1.10, U2.20
NE555_CTRL: C13.1, U36.5
NE555_OUT: R104.1, TP11.1, U36.3
NE555_TRIG: D16.2, R101.2, TP10.1, U36.2
OUT_BE_A: D8.1, J6.7, K4.3, R78.1
OUT_BE_B: C7.2, D8.2, J6.8, K4.4
OUT_M1_A: D14.1, J6.13, K7.3, R87.1
OUT_M1_B: C10.2, D14.2, J6.14, K7.4
OUT_M2_A: D12.1, J6.11, K6.3, R84.1
OUT_M2_B: C9.2, D12.2, J6.12, K6.4
OUT_M_A: D10.1, J6.9, K5.3, R81.1
OUT_M_B: C8.2, D10.2, J6.10, K5.4
OUT_SP_A: D6.1, J6.5, K3.3, R75.1
OUT_SP_B: C6.2, D6.2, J6.6, K3.4
OUT_S_A: D2.1, J6.1, K1.3, R69.1
OUT_S_B: C4.2, D2.2, J6.2, K1.4
OUT_T_A: D4.1, J6.3, K2.3, R72.1
OUT_T_B: C5.2, D4.2, J6.4, K2.4
PI_UART_RX: A1.1, J1.6
PI_UART_TX: A1.2, J1.5
RAIL_GATE: Q14.1, Q15.3, R106.2
RELAY_ENABLE_RAIL: D1.1, D3.1, D5.1, D7.1, D9.1, D11.1, D13.1, K1.1, K2.1, K3.1, K4.1, K5.1, K6.1, K7.1, Q14.3, TP16.1
RP2040_OK: A1.4, J1.13, R109.1, TP14.1
SAFE_STOP_RETURN: J8.4, Q14.2, R106.1, TP15.1
SAFE_TBSC_RETURN: J8.2, J8.3
SLOW_AUX1: R62.2, U2.26, U33.4
SLOW_AUX2: R64.2, U2.27, U34.4
SLOW_AUX3: R66.2, U2.28, U35.4
SLOW_BS: R44.2, U1.5, U24.4
SLOW_FOUL: R50.2, U1.8, U27.4
SLOW_GP: R40.2, U1.3, U22.4
SLOW_GS1: R20.2, U1.21, U12.4
SLOW_GS2: R22.2, U1.22, U13.4
SLOW_GS3: R24.2, U1.23, U14.4
SLOW_GS4: R26.2, U1.24, U15.4
SLOW_GS5: R28.2, U1.25, U16.4
SLOW_GS6: R30.2, U1.26, U17.4
SLOW_GS7: R32.2, U1.27, U18.4
SLOW_GS8: R34.2, U1.28, U19.4
SLOW_GS9: R36.2, U1.1, U20.4
SLOW_GS10: R38.2, U1.2, U21.4
SLOW_MAN_S: R56.2, U2.23, U30.4
SLOW_MAN_SWS: R58.2, U2.24, U31.4
SLOW_MAN_SWSR: R60.2, U2.25, U32.4
SLOW_MAN_T: R54.2, U2.22, U29.4
SLOW_OS: R42.2, U1.4, U23.4
SLOW_PBC: R48.2, U1.7, U26.4
SLOW_PBZ: R46.2, U1.6, U25.4
SLOW_TENTH: R52.2, U2.21, U28.4
SNUB_BE: C7.1, R78.2
SNUB_M: C8.1, R81.2
SNUB_M1: C10.1, R87.2
SNUB_M2: C9.1, R84.2
SNUB_S: C4.1, R69.2
SNUB_SP: C6.1, R75.2
SNUB_T: C5.1, R72.2
VCC_3V3: A1.36, C1.1, C2.1, C3.1, C14.1, J1.11, R1.1, R2.1, R4.1, R6.1, R8.1, R10.1, R12.1, R14.1, R16.1, R18.1, R20.1, R22.1, R24.1, R26.1, R28.1, R30.1, R32.1, R34.1, R36.1, R38.1, R40.1, R42.1, R44.1, R46.1, R48.1, R50.1, R52.1, R54.1, R56.1, R58.1, R60.1, R62.1, R64.1, R66.1, TP3.1, U1.9, U1.18, U2.9, U2.15, U2.18, U3.9, U3.16, U3.18
VCC_5V: A1.39, C12.1, D17.1, J1.1, J7.1, J8.1, R100.1, R101.1, TP1.1, U36.4, U36.8, U37.1
VCC_5V_RAW: D17.2, J2.1
WDOG_KICK: J1.7, R102.1, TP8.1
WDOG_KICK_DRAIN: D15.1, D16.1, Q12.3
WDOG_KICK_GATE: Q12.1, R102.2, R103.1
WDOG_OK_GATE: Q13.1, R104.2, R105.1
WDOG_OK_PULLDOWN: Q13.3, Q16.2, TP12.1
WDOG_TIMING_NODE: C11.1, D15.2, R100.2, TP9.1, U36.6, U36.7

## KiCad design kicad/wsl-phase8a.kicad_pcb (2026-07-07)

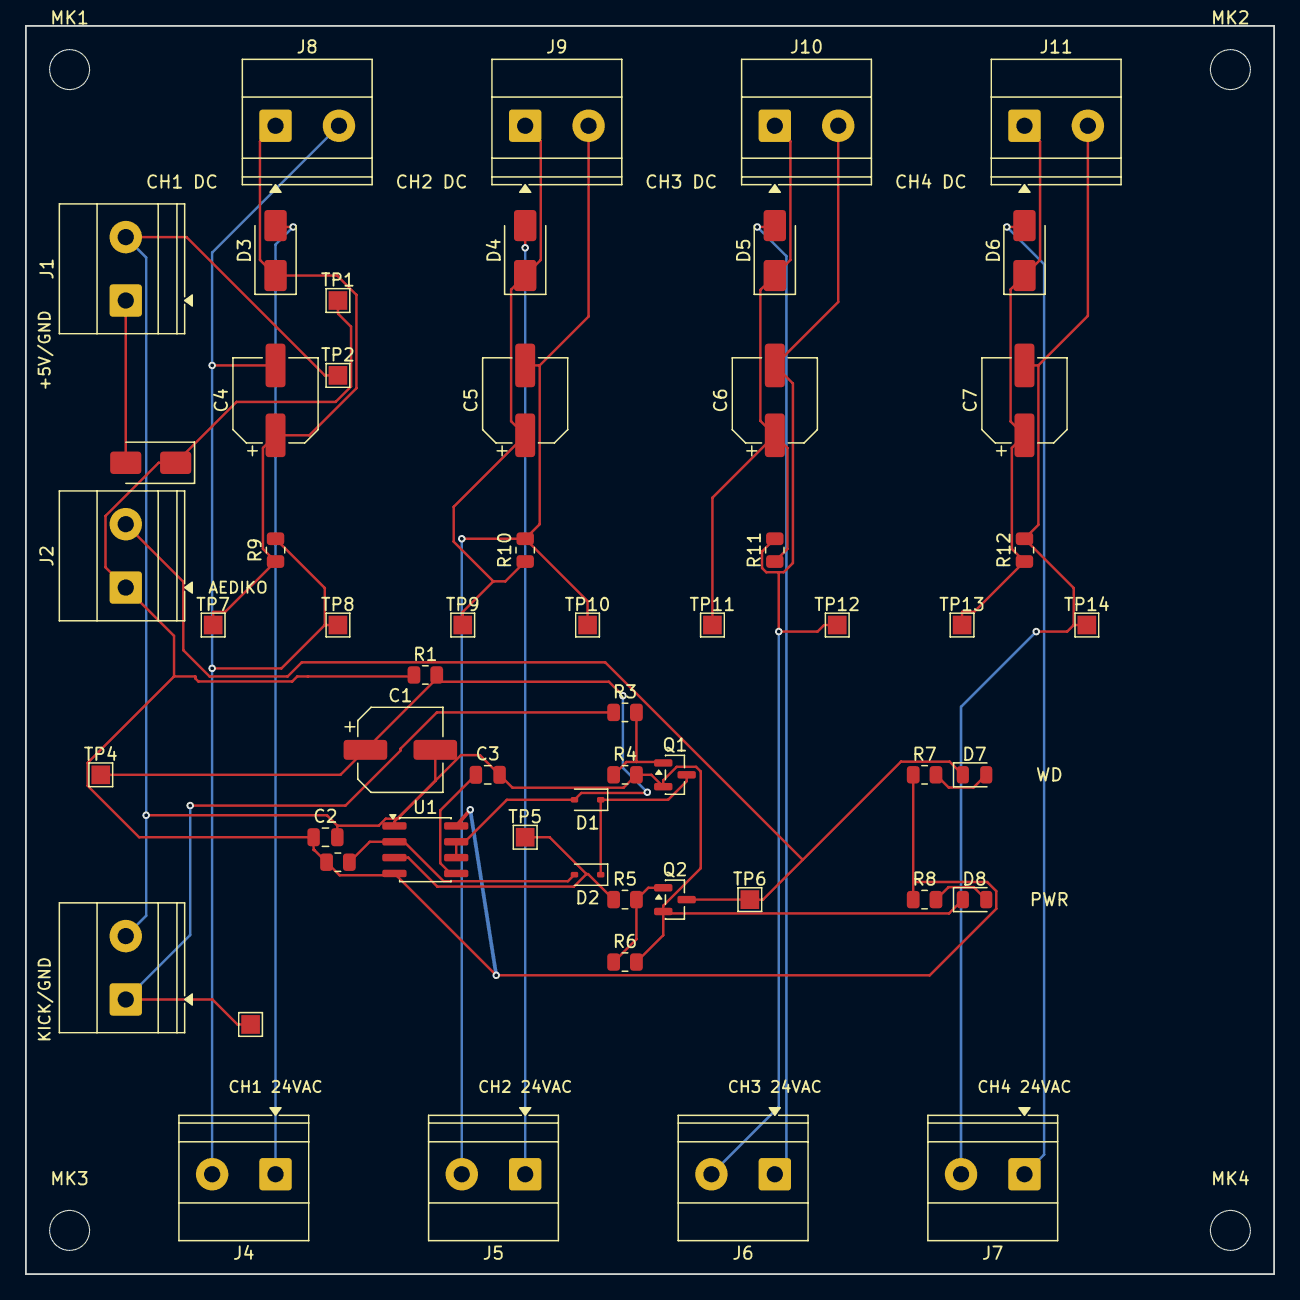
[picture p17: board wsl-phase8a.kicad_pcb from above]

Board: 2 copper layers, 100.0 x 100.0 mm, 60 parts (0 on the bottom side), 26 nets.

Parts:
C1: 100uF/16V; CP_Elec_6.3x5.4
C2: 0.1uF/50V; C_0805_2012Metric
C3: 10nF/50V; C_0805_2012Metric
C4, C5, C6, C7: 10uF/63V; CP_Elec_6.3x5.4
D1, D2: 1N4148WS; D_SOD-323
D3, D4, D5, D6: M7 (1N4007); D_SMA
D7, D8: Green; LED_0805_2012Metric
D9: SS14; D_SMA
J1, J2, J3, J4, J5, J6, J7, J8, J9, J10, J11: 5.08mm 2P TB; TerminalBlock_Phoenix_MKDS-1,5-2-5.08_1x02_P5.08mm_Horizont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
MK1, MK2, MK3, MK4: MountingHole_3.2mm_M3
Q1, Q2: AO3400A; SOT-23
R1, R9, R10, R11, R12: 100k; R_0805_2012Metric
R2, R4, R6: 10k; R_0805_2012Metric
R3, R5: 1k; R_0805_2012Metric
R7, R8: 470; R_0805_2012Metric
TP1: VCC_5V; TestPoint_Pad_1.5x1.5mm
TP2: GND; TestPoint_Pad_1.5x1.5mm
TP3: KICK; TestPoint_Pad_1.5x1.5mm
TP4: TIMING_NODE; TestPoint_Pad_1.5x1.5mm
TP5: NE555_OUT; TestPoint_Pad_1.5x1.5mm
TP6: COIL_GND_RETURN; TestPoint_Pad_1.5x1.5mm
TP7: DC_CH1_POS; TestPoint_Pad_1.5x1.5mm
TP8: CH1_RETURN; TestPoint_Pad_1.5x1.5mm
TP9: DC_CH2_POS; TestPoint_Pad_1.5x1.5mm
TP10: CH2_RETURN; TestPoint_Pad_1.5x1.5mm
TP11: DC_CH3_POS; TestPoint_Pad_1.5x1.5mm
TP12: CH3_RETURN; TestPoint_Pad_1.5x1.5mm
TP13: DC_CH4_POS; TestPoint_Pad_1.5x1.5mm
TP14: CH4_RETURN; TestPoint_Pad_1.5x1.5mm
U1: NE555; SOIC-8_3.9x4.9mm_P1.27mm

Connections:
AC_CH1_L1: D3.2, J4.1
AC_CH2_L1: D4.2, J5.1
AC_CH3_L1: D5.2, J6.1
AC_CH4_L1: D6.2, J7.1
CH1_RETURN: C4.2, J4.2, J8.2, R9.2, TP8.1
CH2_RETURN: C5.2, J5.2, J9.2, R10.2, TP10.1
CH3_RETURN: C6.2, J6.2, J10.2, R11.2, TP12.1
CH4_RETURN: C7.2, J7.2, J11.2, R12.2, TP14.1
COIL_GND_RETURN: D7.1, J2.2, Q2.3, TP6.1
DC_CH1_POS: C4.1, D3.1, J8.1, R9.1, TP7.1
DC_CH2_POS: C5.1, D4.1, J9.1, R10.1, TP9.1
DC_CH3_POS: C6.1, D5.1, J10.1, R11.1, TP11.1
DC_CH4_POS: C7.1, D6.1, J11.1, R12.1, TP13.1
GND: C1.2, C2.2, C3.2, D8.1, J1.2, J3.2, Q1.2, Q2.2, R4.2, R6.2, TP2.1, U1.1
KICK: J3.1, R3.1, TP3.1
LED1_ANODE_DRIVE: D7.2, R7.2
LED2_ANODE_DRIVE: D8.2, R8.2
NE555_CTRL: C3.1, U1.5
NE555_OUT: R5.1, TP5.1, U1.3
NE555_TRIG: D2.2, R2.2, U1.2
Q1_DRAIN: D1.1, D2.1, Q1.3
Q1_GATE: Q1.1, R3.2, R4.1
Q2_GATE: Q2.1, R5.2, R6.1
TIMING_NODE: C1.1, D1.2, R1.2, TP4.1, U1.6, U1.7
VCC_5V: C2.1, D9.1, J2.1, R1.1, R2.1, R7.1, R8.1, TP1.1, U1.4, U1.8
VCC_5V_RAW: D9.2, J1.1

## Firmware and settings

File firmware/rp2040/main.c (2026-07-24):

/*
 * WSL Phase 8b — RP2040 lane-controller co-processor — firmware v0.1.0
 * =====================================================================
 * One RP2040 (Pico module) per lane on the rev-B controller board. It is the
 * FAST + SAFETY half of the controller; the Raspberry Pi runs the cycle FSM
 * (lane_node/cycle_control_8270.py) over an MCP23017/relay path. This firmware:
 *
 *   1. Reads the 8 fast inputs (6 cams + 2 DIELL ball beams), de-bounces them,
 *      and PUSHES edge events to the Pi over uart0 (the FSM consumes events, it
 *      does not poll — removes Pi-scheduling latency from cam timing).
 *   2. Drives RP2040_OK (GP2) = the rail-permission line in the relay-enable-rail
 *      AND chain. HIGH only when healthy; LOW on boot, fault, or hang. This is a
 *      first-class, non-bypassable safety-rail condition (spec §4.1/§4.2).
 *   3. Provides the RP2040's UART-INDEPENDENT safety contributions:
 *        - firmware health (RP2040 hardware watchdog: a hung loop resets the chip
 *          -> GP2 goes Hi-Z -> external 100k pulldown -> rail drops);
 *        - motion max-run backstop ("cam timeout"): if the Pi marks a guarded
 *          motor RUNNING (RUN <m>) and never STOPs it within MAX_MOTION_MS, the
 *          firmware latches a fault and drops RP_OK.
 *   4. Heartbeats to the Pi so a dead/!ok RP2040 is detected (Pi then drops ARM).
 *
 * SAFETY MODEL (read before editing — sources: docs/phase8b_pcb_revB_spec.md §4,
 * docs/phase8_8270_SYSTEM_REFERENCE.md §5):
 *   - This board is NEVER the only safety device for the Stop/CIS/master-breaker
 *     chain, the NE555 watchdog (watches the *Pi*), or regenerative motor
 *     braking — those are in hardware, independent of this firmware. The TB/SC
 *     collision interlock is the EXCEPTION: it is PLANNED hardware only — design
 *     open per docs/phase8_interlock_redesign.md (measured 2026-06-27: the
 *     J_SAFETY NC loop is unbuildable as drawn). Until it lands, the software
 *     echo is the ONLY TB/SC guard.
 *   - RP_OK is FAIL-SAFE LOW. Telemetry must NEVER block the safety loop: UART TX
 *     is a non-blocking ring buffer; the RP_OK drive + watchdog kick run every
 *     loop pass regardless of UART state. A dead UART cannot cause unsafe motion
 *     (no RUN msgs -> nothing marked running; and the Pi's own motion-timeout
 *     FAULT drops ARM).
 *
 * DEFERRED to v1.1 (NOT in this firmware, on purpose):
 *   - Cam-stop OVERRUN enforcement (stop-cam fires while a motor is RUNNING and
 *     the Pi fails to STOP within a grace window -> drop RP_OK). It needs the
 *     per-cam edge->angle polarity that is a deferred cutover field item
 *     (phase8_trackB_controller_cutover_runbook.md §3.2). Do NOT bake in unconfirmed
 *     cam polarity. The hook is marked  // v1.1  below.
 *   - SC/TB collision echo gating RP_OK (the hardware J_SAFETY loop is PLANNED
 *     only — design open per docs/phase8_interlock_redesign.md; the firmware
 *     echo is enabled once the SC/TB windows are bench-confirmed).
 *
 * This firmware is bench-bring-up gated (spec §12.9) before any live machine.
 */
#include <stdio.h>
#include <string.h>
#include <stdarg.h>

#include "pico/stdlib.h"
#include "hardware/uart.h"
#include "hardware/gpio.h"
#include "hardware/watchdog.h"
#include "hardware/adc.h"       /* v1.2: VCC_5V sense on GP26/ADC0            */
#include "hardware/sync.h"      /* v1.2: IRQ-safe tap-ring snapshot/clear     */
#include "hardware/structs/io_bank0.h"  /* v1.2.2: CTRL.OEOVER + STATUS.OETOPAD readback (R2-1) */
#include "pico/unique_id.h"     /* v1.2.2: Pico unique board id (identity line, R2-6) */
#include "hardware/structs/rosc.h"  /* v1.2.3: ROSC randombit entropy for the boot nonce (R3-5) */

#ifdef WSL_EMBED_BUILD_ID
#include "build_id.h"           /* controlled-input WSL_BUILD_ID / WSL_CFG_SHA */
#endif

#include "config.h"

#define UART_ID uart0

/* compile-time printf-format checking on the event logger (emit) */
#if defined(__GNUC__) || defined(__clang__)
#define EMIT_FMT __attribute__((format(printf, 1, 2)))
#else
#define EMIT_FMT
#endif

/* ====================================================================== */
/*  Time helpers                                                          */
/* ====================================================================== */
static inline uint32_t now_ms(void) { return to_ms_since_boot(get_absolute_time()); }

/* ====================================================================== */
/*  Non-blocking UART TX ring  (telemetry must never stall the safety loop)*/
/* ====================================================================== */
#define TXR_SZ 1024   /* v1.2: 512 -> 1024 (hb line grew; TXR_HEADROOM grew in lockstep) */
static uint8_t  txr[TXR_SZ];
static uint16_t txr_head = 0, txr_tail = 0;
static uint32_t txr_drops = 0;     /* whole lines dropped because the ring was full */

static uint16_t txr_free(void) { return (uint16_t)((txr_tail - txr_head - 1u + TXR_SZ) % TXR_SZ); }

/* Enqueue a whole line or none (never a partial line -> Pi parser never sees a torn JSON). */
static void txr_push(const char *s, int n) {
    if (n <= 0) return;
    if (txr_free() < (uint16_t)n) { txr_drops++; return; }
    for (int i = 0; i < n; i++) { txr[txr_head] = (uint8_t)s[i]; txr_head = (uint16_t)((txr_head + 1u) % TXR_SZ); }
}

/* Drain as many bytes as the UART FIFO will take this pass; never blocks. */
static void txr_drain(void) {
    while (txr_head != txr_tail && uart_is_writable(UART_ID)) {
        uart_putc_raw(UART_ID, (char)txr[txr_tail]);
        txr_tail = (uint16_t)((txr_tail + 1u) % TXR_SZ);
    }
}

/* Format an event line (caller includes the trailing '\n') and enqueue it.
 * A line that does not fit fmtbuf is dropped WHOLE (counted in txr_drops) —
 * never truncated, because a torn line without its '\n' would glue onto the
 * next line at the Pi parser and corrupt BOTH.
 *   emit()     — critical lines (boot/hb/flt/rp_ok/ack): may fill the ring.
 *   emit_evt() — cam/ball telemetry: only enqueued while TXR_HEADROOM bytes
 *                stay free, so an event flood can never starve hb/flt/rp_ok. */
/* SIZE BUDGET (re-counted for v1.2.3, 2026-07-23): the longest single lines are
 *   boot = ~147 B v1.1.1 worst + 36 B tap{} block + 16 B bn  = ~199 B worst
 *   hb   = ~110 B v1.1.1 worst + ~64 B tap/rd/ep/v5* + 10 B rid
 *          + 16 B bn                                          = ~200 B worst
 *   id   = ~85 B fixed + fw 21 + bn 16 + pcb 7 + rid 3 + uid 16 + build<=32
 *          + cfg<=16 + t 10 (build/cfg/uid are %.Ns-capped)   = ~206 B worst
 * fmtbuf 256 (~50 B margin). If you ADD A FIELD, re-count the worst case or the
 * whole line silently drops (visible only as txr_drops) and the Pi loses it.
 * Grow fmtbuf with the line, never trust it silently. TXR_HEADROOM (320) must
 * stay >= the worst flt+rp_ok+hb burst (~60+40+200 = 300) — re-check it too. */
static char fmtbuf[256];
static void emit_v(bool lowprio, const char *fmt, va_list ap) {
    int n = vsnprintf(fmtbuf, sizeof(fmtbuf), fmt, ap);
    if (n <= 0) return;
    if (n >= (int)sizeof(fmtbuf)) { txr_drops++; return; }      /* drop whole, never tear */
    if (lowprio && txr_free() < (uint16_t)(n + TXR_HEADROOM)) { txr_drops++; return; }
    txr_push(fmtbuf, n);
#if DEBUG_USB
    fwrite(fmtbuf, 1, (size_t)n, stdout);
#endif
}
static void emit(const char *fmt, ...) EMIT_FMT;
static void emit(const char *fmt, ...) {
    va_list ap; va_start(ap, fmt); emit_v(false, fmt, ap); va_end(ap);
}
static void emit_evt(const char *fmt, ...) EMIT_FMT;
static void emit_evt(const char *fmt, ...) {
    va_list ap; va_start(ap, fmt); emit_v(true, fmt, ap); va_end(ap);
}

/* ====================================================================== */
/*  v1.2.2 pad-level output-enable lock (Codex R2-1)                       */
/* ====================================================================== */
/* The v1.2.0/v1.2.1 input-only invariant read back the SIO OE + IO-bank
 * function registers ONLY. The RP2040's per-pin CTRL.OEOVER field bypasses
 * both: OEOVER=ENABLE/HIGH forces the pad's output-enable ON at the pad
 * regardless of the SIO direction, so a rogue write to one IO_BANK0 CTRL
 * register could drive an "input-only" pin while the old readback stayed
 * green. Fix (R2-1):
 *   - force_pad_input_only() is the ONE lock point: CTRL.OEOVER = DISABLE.
 *     Called LAST in each pin-config choke point (gpio_init/gpio_set_function
 *     rewrite the whole CTRL register and would silently clear the override —
 *     ordering is load-bearing; the host mock mirrors that clearing).
 *   - pad_oe_locked() verifies BOTH the CTRL.OEOVER field still reads
 *     DISABLE AND the live pad STATUS.OETOPAD bit reads 0 (the actual
 *     output-enable reaching the pad). Checked at init and every heartbeat
 *     tick by tap_assert_input_only() for EVERY input-contract pin (taps
 *     GP16-19, ADC GP26, fast inputs GP6-13, REV_ID GP20-21); drift latches
 *     a fail-safe "pad_oe" fault -> RP_OK drops.                            */
static void force_pad_input_only(uint p) { gpio_set_oeover(p, GPIO_OVERRIDE_LOW); }

static bool pad_oe_locked(uint p) {
    uint32_t ctrl = io_bank0_hw->io[p].ctrl;
    if (((ctrl & IO_BANK0_GPIO0_CTRL_OEOVER_BITS) >> IO_BANK0_GPIO0_CTRL_OEOVER_LSB)
        != IO_BANK0_GPIO0_CTRL_OEOVER_VALUE_DISABLE)
        return false;
    return (io_bank0_hw->io[p].status & IO_BANK0_GPIO0_STATUS_OETOPAD_BITS) == 0u;
}

/* ====================================================================== */
/*  Fast inputs: time-based debounce + edge detection                     */
/* ====================================================================== */
/* Ring capacity for the SLIDING chatter window: must cover the largest per-
 * input budget. 8 inputs x 32 x 4 B = 1 KB static — trivial on the RP2040. */
#define CHATTER_RING_MAX 32u
#if CHATTER_MAX_CAM > CHATTER_RING_MAX || CHATTER_MAX_DIELL > CHATTER_RING_MAX
#error "CHATTER_RING_MAX must cover the largest CHATTER_MAX_* budget"
#endif

typedef struct {
    const char *id;
    uint        gpio;
    uint32_t    debounce_us;
    bool        is_ball;        /* DIELL beams -> coalesced into one "ball" event */
    uint8_t     chatter_max;    /* max debounced edges per CHATTER_WINDOW_MS before fault */
    /* runtime */
    bool        stable_asserted;
    bool        cand_asserted;
    uint64_t    cand_since_us;
    /* sliding chatter window: timestamps of the last chatter_max debounced edges */
    uint32_t    edge_ring[CHATTER_RING_MAX];
    uint8_t     ring_n;         /* edges recorded so far (saturates at chatter_max) */
    uint8_t     ring_i;         /* next write slot = the OLDEST recorded edge once full */
} input_t;

static input_t inputs[] = {
    { "SA",      PIN_SA,      DEBOUNCE_CAM_US,   false, CHATTER_MAX_CAM,   false, false, 0, {0}, 0, 0 },
    { "SB",      PIN_SB,      DEBOUNCE_CAM_US,   false, CHATTER_MAX_CAM,   false, false, 0, {0}, 0, 0 },
    { "SC",      PIN_SC,      DEBOUNCE_CAM_US,   false, CHATTER_MAX_CAM,   false, false, 0, {0}, 0, 0 },
    { "TA1",     PIN_TA1,     DEBOUNCE_CAM_US,   false, CHATTER_MAX_CAM,   false, false, 0, {0}, 0, 0 },
    { "TA2",     PIN_TA2,     DEBOUNCE_CAM_US,   false, CHATTER_MAX_CAM,   false, false, 0, {0}, 0, 0 },
    { "TB",      PIN_TB,      DEBOUNCE_CAM_US,   false, CHATTER_MAX_CAM,   false, false, 0, {0}, 0, 0 },
    { "DIELL_L", PIN_DIELL_L, DEBOUNCE_DIELL_US, true,  CHATTER_MAX_DIELL, false, false, 0, {0}, 0, 0 },
    { "DIELL_R", PIN_DIELL_R, DEBOUNCE_DIELL_US, true,  CHATTER_MAX_DIELL, false, false, 0, {0}, 0, 0 },
};
#define N_INPUTS (sizeof(inputs) / sizeof(inputs[0]))

static uint32_t last_ball_ms = 0;

static void latch_fault(const char *code, const char *motor);   /* defined below */
static void camstop_on_cam_edge(const char *cam_id, char edge); /* v1.1, defined below */

/* Round-3 boot-order fix (Codex 2026-07-21 PM, finding 1): the fast inputs
 * GP6-13 join the tap_assert_input_only() contract set only AFTER init_inputs()
 * has configured them. main() runs the first invariant pass BEFORE init_inputs()
 * (taps/ADC must be enforced from the first moment), and at that point GP6-13
 * are still at silicon reset state (FUNCSEL=NULL, not SIO) — an ungated check
 * latched a spurious "tap_dir"/SA fault on EVERY boot of the v1.2.2 image and
 * refused RP_OK until an operator PBZ. Same pattern as rev_id_inited. */
static bool inputs_inited = false;

static void init_inputs(void) {
    uint64_t t = time_us_64();
    for (size_t i = 0; i < N_INPUTS; i++) {
        input_t *in = &inputs[i];
        gpio_init(in->gpio);
        gpio_set_dir(in->gpio, GPIO_IN);
        /* Rev-D's external 47k is the authoritative pull-up. Enabling the
         * RP2040's ~50-80k internal pull in parallel would cut the effective
         * resistance to ~24-30k and invalidate the qualified optocoupler
         * current margin. A missing external pull-up is a board fault, not a
         * condition firmware should mask. */
        gpio_disable_pulls(in->gpio);
        force_pad_input_only(in->gpio);         /* v1.2.2 R2-1: OEOVER=DISABLE, LAST (see lock section) */
        bool asserted = (gpio_get(in->gpio) == 0);   /* active-low */
        in->stable_asserted = asserted;
        in->cand_asserted   = asserted;
        in->cand_since_us   = t;
        in->ring_n          = 0;
        in->ring_i          = 0;
    }
    inputs_inited = true;       /* pins now in the invariant contract set */
}

/* Debounced asserted level of an input by id (false if the id is unknown). Used by the v1.1
 * SC/TB interlock echo in supervise() — level-based, robust vs a single dropped cam edge. */
static bool input_asserted(const char *id) {
    for (size_t i = 0; i < N_INPUTS; i++)
        if (strcmp(inputs[i].id, id) == 0) return inputs[i].stable_asserted;
    return false;
}
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
int main(void) {
#if DEBUG_USB
    stdio_init_all();   /* USB-CDC only (uart stdio disabled in CMake) */
#endif

    /* RP_OK LOW first, before anything else — fail-safe (rail stays dead during init).
     * This is the ONE deliberate exception to R3.2's "tap_init before any other GPIO
     * configuration": the fail-safe RP_OK drive is the stronger invariant, GP2 is not
     * a tap pin, and the taps are input-only from reset anyway (RP2040 pads reset with
     * output disabled) — tap_init() only ever NARROWS their configuration. */
    gpio_init(PIN_RP_OK);
    gpio_set_dir(PIN_RP_OK, GPIO_OUT);
    gpio_put(PIN_RP_OK, 0);

    /* v1.2: adopt/zero the noinit tap ring BEFORE tap IRQs can write it, then the
     * tap choke-point init — ahead of every other GPIO configuration (R3.2). */
    bool wdt_reboot = watchdog_caused_reboot();
    tap_boot_init(wdt_reboot);
    tap_init();
    rev_id_init();              /* v1.2.2 R2-6: strap read; pins then join the contract set */
    identity_init();            /* v1.2.2 R2-6: capture the Pico unique id                  */
    boot_nonce_init();          /* v1.2.3 R3-5: per-boot nonce (boot/id/hb "bn")            */
    tap_assert_input_only();    /* enforced from the first moment (latches on drift) */

    /* uart0 to the Pi (protocol transport; NOT stdio). */
    uart_init(UART_ID, UART_BAUD);
    gpio_set_function(PIN_UART_TX, GPIO_FUNC_UART);
    gpio_set_function(PIN_UART_RX, GPIO_FUNC_UART);
    uart_set_hw_flow(UART_ID, false, false);
    uart_set_format(UART_ID, 8, 1, UART_PARITY_NONE);
    uart_set_fifo_enabled(UART_ID, true);

    init_inputs();
    tap_assert_input_only();    /* GP6-13 joined the contract set — verify immediately
                                 * (round-3 boot-order fix; the line above pre-inputs
                                 * covers taps/ADC/REV_ID only) */
    init_camstops();        /* v1.1: resolve cam-stop descriptor motor pointers + disarm */
#if FI1_ENABLED
    fi1_init();             /* v1.2.2 bench build: physical-jumper gate (permanent refusal) */
#endif
    boot_ms = now_ms();

    /* maxrun_ms: the Pi must verify its MAX_MOTION_S does not exceed this at
     * link-up (the firmware backstop is an independent compile-time copy).
     * dbg: 1 = DEBUG_USB build, so a debug image at the lane is visible.
     * v11 (v1.1.1): the v1.1 enforcement posture — an ARMED build must be
     * on-the-wire distinguishable from a stock build (FW_VERSION is identical
     * for both). sa/ta1 = "off" | the trip edge ("f"/"r"/"?"); echo/nrun =
     * INTERLOCK_ECHO_ENABLED / MOTION_NO_RUN_ENABLED.
     * tap (v1.2): noinit-ring boot semantics (R3.3) — ep = epoch, pre = 1 if a
     * valid pre-reboot ring was ADOPTED (0 = zeroed: power loss/first boot),
     * n = preserved entry count. wdt_reset (v0.2.0) is the boot-reason capture.
     * All additive fields: older Pi-side parsers ignore unknown keys. */
    char sa_p[4], ta1_p[4];
    camstop_posture_str(sa_p,  (bool)CAM_SA_STOP_ENABLED,  CAM_SA_TRIP);
    camstop_posture_str(ta1_p, (bool)CAM_TA1_STOP_ENABLED, CAM_TA1_TRIP);
    /* v1.2.3 (R3-5): "bn" = the per-boot nonce. The tap ring epoch resets to 1
     * on power loss, so it is NOT a boot identity; bn is fresh every boot and
     * repeated on every hb, making a missed boot line detectable within one
     * heartbeat. The boot line + this nonce are the Pi's cache-invalidation
     * epoch signal (rp2040_link must drop ALL cached identity/capability
     * state whenever bn changes or a boot line arrives).                    */
    emit("{\"ev\":\"boot\",\"fw\":\"%s\",\"bn\":%lu,\"wdt_reset\":%d,\"rp_ok\":0,\"maxrun_ms\":%lu,\"dbg\":%d,"
         "\"v11\":{\"sa\":\"%s\",\"ta1\":\"%s\",\"echo\":%d,\"nrun\":%d},"
         "\"tap\":{\"ep\":%lu,\"pre\":%d,\"n\":%lu}}\n",
         FW_VERSION, (unsigned long)fw_boot_nonce,
         wdt_reboot ? 1 : 0, (unsigned long)MAX_MOTION_MS, DEBUG_USB ? 1 : 0,
         sa_p, ta1_p, INTERLOCK_ECHO_ENABLED ? 1 : 0, MOTION_NO_RUN_ENABLED ? 1 : 0,
         (unsigned long)tap_ring.epoch, tap_ring_preserved ? 1 : 0,
         (unsigned long)tap_ring.count);
    emit_id();              /* v1.2.2 R2-6: identity line follows the boot line */

    /* RP2040 hardware watchdog: if the loop ever hangs, the chip resets -> GP2 goes
     * Hi-Z -> external 100k pulldown holds the rail DEAD -> motion stops. */
    watchdog_enable(WDT_TIMEOUT_MS, 1);

    uint32_t last_hb = now_ms();
    uint32_t last_adc = last_hb;

    for (;;) {
        watchdog_update();      /* keep the chip alive only while the loop runs */
        scan_inputs();          /* debounce + push cam/ball events             */
        poll_uart();            /* RUN/STOP/CLEAR/PING/TAPDUMP/TAPCLR from Pi  */
#if FI1_ENABLED
        fi1_service();          /* v1.2.3 R3-6: FI-1 dead-man supervision —
                                 * arm/drive timeout, UART loss, KA token.
                                 * AFTER poll_uart (so this pass sees the
                                 * freshest RX/KA stamps and cannot release on
                                 * data that already arrived) and BEFORE
                                 * supervise() (so an auto-release that
                                 * re-latches a pad fault drops RP_OK in the
                                 * SAME pass, not one loop later).            */
#endif
        supervise();            /* compute + drive RP_OK (fail-safe)           */
        txr_drain();            /* push queued telemetry, non-blocking         */
        tap_service();          /* v1.2: IRQ un-mute + drip tap-ring dump      */

        uint32_t m = now_ms();
        if ((uint32_t)(m - last_adc) >= ADC_VCC5_SAMPLE_MS) {   /* v1.2: 10 Hz VCC_5V */
            last_adc = m;
            adc_vcc5_sample();
        }
        if ((uint32_t)(m - last_hb) >= HB_INTERVAL_MS) {
            last_hb = m;
            tap_hb_tick();      /* v1.2: direction invariant + RPOK cross-check */
            emit_hb();
            adc_v5_window_reset();
        }
    }
    /* not reached */
}

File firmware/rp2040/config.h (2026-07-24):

/*
 * WSL Phase 8b — RP2040 lane-controller co-processor — pin + timing + protocol contract
 *
 * AUTHORITATIVE PIN MAP SOURCE: scripts/generate_kicad_netlist_revB.py, block_rp2040()
 * (the LIVE board netlist generator). Physical Pico pin -> GPIO verified against the
 * KiCad "Module:RaspberryPi_Pico_SMD" footprint. If the board netlist changes, re-verify
 * these against block_rp2040() before flashing — do NOT trust the older draft in
 * docs/phase8_channel_allocation.md §2, which assigned the fast inputs to GP0-GP7 (WRONG
 * vs the as-built board; the real board uses GP6-GP13).
 *
 * Electrical sense (from generate_kicad_netlist_revB.py opto_input()): every fast input is
 * opto-isolated and ACTIVE-LOW at the Pico — machine contact CLOSED (signal asserted) pulls
 * the GPIO LOW; idle is HIGH (rev-D: on-board 47k pull-up to 3V3; RP2040 internal pull
 * DISABLED so it cannot reduce the qualified resistance). RP2040_OK (GP2) drives an NPN in
 * the relay-enable-rail AND chain: HIGH = permit motion, LOW = drop the rail. A 100k base
 * pulldown makes the rail fail-safe-dead whenever GP2 is Hi-Z (unpowered / in reset / pre-init).
 */
#ifndef WSL_PHASE8B_RP2040_CONFIG_H
#define WSL_PHASE8B_RP2040_CONFIG_H

/* v1.2.3 (2026-07-23, Codex round-3 remediation R3-6 + firmware half of R3-5 — NOT flashed):
 *   - CLEAR pad-revalidation gate (R3-6): the CLEAR handler now SYNCHRONOUSLY
 *     re-runs the full input-only invariant (SIO dir + funcsel + OEOVER +
 *     OETOPAD on every contract pin) BEFORE clearing any fault — a persistent
 *     pad violation makes CLEAR a no-op answered with a "nak" line, the fault
 *     stays latched and RP_OK stays low. Closes the Codex window where CLEAR
 *     unconditionally cleared and RP_OK could reassert for up to one hb tick
 *     (250 ms) with a driveable "input" pad.
 *   - FI-1 dead-man hardening (R3-6, bench build only): arm timeout (ARM with
 *     no DRIVE auto-disarms), drive timeout (max continuous injection), UART-
 *     loss release (RX-idle link-dead detection releases injection), and a
 *     continuous dead-man ("FI1 KA" token required while driving). Every
 *     auto-release restores the locked input-only contract and re-verifies it.
 *   - Boot-epoch nonce (firmware half of R3-5): a per-boot 32-bit nonce
 *     (ROSC entropy ^ boot time, never 0) in a new additive "bn" field on the
 *     boot line, the id line AND every heartbeat — the Pi can detect a missed
 *     boot line within one hb and invalidate ALL cached identity/capability
 *     state (identity itself is re-emitted after every boot and on "ID").
 * ALL ADDITIVE line formats; no safety path weakened (the CLEAR gate only ever
 * REFUSES a recovery). See CHANGELOG.md.
 *
 * v1.2.2 (2026-07-21, Codex round-2 remediation R2-1 + R2-13 — NOT flashed):
 *   - PAD-LEVEL output lock (R2-1): CTRL.OEOVER is forced to DISABLE on every
 *     input-contract pin (taps GP16-19, ADC GP26, fast inputs GP6-13, REV_ID
 *     GP20-21) and the invariant readback now ALSO verifies the OEOVER field +
 *     the pad STATUS.OETOPAD bit — the v1.2.0/v1.2.1 check read only the SIO
 *     direction, which an OEOVER override bypasses entirely at the pad.
 *   - Epoch-aware rail-drop classifier (R2-13): tap_classify() now excludes
 *     pre-reboot (cross-epoch) ring entries — they stay in the dump as
 *     history, but can never influence a fresh cause code.
 *   - FI-1 bench fault-injection hook (R2-13/R1.9): compile-flag gated
 *     (FI1_ENABLED, default OFF = zero code compiled in), BOOTSEL-jumper +
 *     arm-command gated at runtime, drives GP16-19 output-high on command for
 *     the FA-7 unidirectionality proof. NEVER a release artifact.
 *   - Identity line (R2-6): REV_ID strap read (GP20/GP21), Pico unique ID,
 *     build git-describe + config.h hash in a new additive "id" line + hb
 *     "rid" field.
 * ALL ADDITIVE line formats; safety paths unchanged except the new fail-safe
 * pad_oe fault direction. See CHANGELOG.md.
 *
 * v1.2.1 (2026-07-21): TAP_KICK_STARVE_MS 300 -> 2000 ms — the 300 value was sized
 * against HB_INTERVAL_MS (the RP2040 heartbeat) mistaken for the Pi kick cadence; the
 * REAL Pi kick is 1 Hz, so 300 ms misclassified ~65 % of genuine 555 drops as
 * kick_starvation. Advisory-classifier-only change; no safety path touched.
 *
 * v1.2.0 (2026-07-21, rev-D remediation R3 — closes Codex finding C2, NOT yet flashed):
 * GP16-19 rev-D diagnostic taps get an ENFORCED input-only init (tap_init choke point +
 * tap_assert_input_only register readback each heartbeat), inverted-tap decode (2N7002
 * common-source stage: raw pad 0 = observed net HIGH), a 1 ms-timestamped rail-drop edge
 * ring in noinit RAM (survives reboot; validity magic + epoch), and VCC_5V ADC sampling
 * on GP26. ALL ADDITIVE: v1.1 line formats unchanged, v1.1 enforcement flags still
 * DEFAULT OFF — a default build adds no NEW enforcement beyond the tap direction
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

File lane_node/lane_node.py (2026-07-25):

#!/usr/bin/env python3
"""Lane node daemon — Pi side. Reads sensors, drives outputs, talks to WSL-SRV.

Each Pi node controls one PAIR of lanes (e.g., lanes 21 + 22). The pair is
selected via mandatory WSL_LANES (e.g. WSL_LANES="23,24"). Per-lane GPIO
assignments live in LANE_GPIO; gpiozero devices and per-lane callbacks are
instantiated by iterating LANES at startup. Server commands carry a `lane`
field that routes to the right physical GPIO.
"""

import asyncio
from concurrent.futures import ThreadPoolExecutor
from datetime import datetime, timezone
import hmac
import json
import logging
import math
import signal
import threading
import time
import uuid

from gpiozero import Button, LED
from websockets.asyncio.client import connect

# pin_detect: numpy pin-classification (DualDeckDetector → 10-bit mask per deck).
# camera: owns the T-Camera capture handle + the calibrated detector + the empty
# reference, and maps deck→lane. detect_current_pins() below uses it in camera
# mode; manual mode never touches it. Both import without cv2/gpiozero present
# (cv2 is lazy in camera.py), so this file still loads on a camera-less bench.
import sys as _sys
from pathlib import Path as _Path
_sys.path.insert(0, str(_Path(__file__).resolve().parent))
import pin_detect
import camera
from reliable_transport import (
    DurableTransport, default_transport_path)
from strict_json import loads as strict_json_loads

logging.basicConfig(level=logging.INFO,
                    format='%(asctime)s [%(levelname)s] %(message)s')
log = logging.getLogger('lane_node')

import os
# SERVER_URL: defaults to localhost for dev (server + node on same Pi),
# overridable via env var for production where the server runs on
# WSL-SRV. Example for production (the live WSL-SRV IP is tracked in ONE
# authoritative place: docs/manual_src/20_operations.md § 20.4):
#   WSL_LANE_SERVER_URL=ws://<WSL-SRV-IP>:8765 python3 lane_node.py
SERVER_URL = os.environ.get("WSL_LANE_SERVER_URL", "ws://localhost:8765")


def _required_node_id(raw):
    """Require the stable fleet identity used by routing and diagnostics."""
    value = (raw or "").strip()
    lowered = value.lower()
    if (
        not value
        or len(value) > 128
        or any(
            not char.isascii()
            or not (char.isalnum() or char in "._:-")
            for char in value
        )
        or lowered == "dev"
        or lowered.startswith("dev-")
        or lowered.endswith("-dev")
        or "-dev-" in lowered
    ):
        raise SystemExit(
            "WSL_LANE_NODE_ID must be an explicit stable production node id")
    return value


NODE_ID = _required_node_id(os.environ.get("WSL_LANE_NODE_ID"))


def _canonical_diag_source(node_id, raw):
    value = (raw or "").strip()
    if value and value != node_id:
        raise SystemExit(
            "WSL_DIAG_SOURCE_ID must exactly equal WSL_LANE_NODE_ID")
    return node_id


os.environ["WSL_DIAG_SOURCE_ID"] = _canonical_diag_source(
    NODE_ID, os.environ.get("WSL_DIAG_SOURCE_ID"))
SCORING_BOOT_ID = uuid.uuid4().hex

def _parse_lanes(raw):
    """Parse WSL_LANES (e.g. "23,24") into a lane-id list.

    Unset, blank, or malformed input is a hard startup error. Falling back to
    a default pair on a provisioning typo could actuate the WRONG physical
    machines' relays. Dead node > wrong machine. (Each lane must also have a
    LANE_GPIO entry — validated below.)
    """
    raw = (raw or "").strip()
    if not raw:
        raise SystemExit(
            "WSL_LANES is required; no physical pair may be guessed")
    try:
        lanes = [int(p) for p in raw.split(",") if p.strip()]
    except ValueError:
        raise SystemExit(f"WSL_LANES={raw!r}: not a comma-separated list of lane numbers")
    if not lanes:
        raise SystemExit(f"WSL_LANES={raw!r}: no lanes parsed")
    if len(set(lanes)) != len(lanes):
        raise SystemExit(f"WSL_LANES={raw!r}: duplicate lane ids")
    lanes = sorted(lanes)
    if (
        len(lanes) != 2
        or lanes[0] < 1
        or lanes[1] > 32
        or lanes[0] % 2 != 1
        or lanes[1] != lanes[0] + 1
    ):
        raise SystemExit(
            f"WSL_LANES={raw!r}: expected one consecutive odd/even lane pair")
    return lanes

LANES = _parse_lanes(os.environ.get("WSL_LANES"))
# Shared LANE_NODE_TOKEN authenticates HTTP diagnostics and server->node
# commands. The distinct WSL_SCORING_NODE_TOKEN authenticates this Pi's HELLO
# identity; reusing the shared token would let any enrolled Pi claim any pair.
LANE_NODE_TOKEN = os.environ.get("LANE_NODE_TOKEN", "").strip()
ALLOW_UNAUTHENTICATED_BENCH = (
    os.environ.get("WSL_ALLOW_UNAUTHENTICATED_BENCH", "").strip() == "1")
if not LANE_NODE_TOKEN and not ALLOW_UNAUTHENTICATED_BENCH:
    raise SystemExit(
        "LANE_NODE_TOKEN is required; set "
        "WSL_ALLOW_UNAUTHENTICATED_BENCH=1 only on an isolated bench")


def _scoring_node_token(
        raw, allow_unauthenticated_bench, shared_token=None):
    token = (raw or "").strip()
    if token and (
        not 16 <= len(token) <= 512
        or any(ord(char) < 33 or ord(char) > 126 for char in token)
    ):
        raise SystemExit(
            "WSL_SCORING_NODE_TOKEN must be 16..512 printable ASCII "
            "characters")
    if not token and not allow_unauthenticated_bench:
        raise SystemExit(
            "WSL_SCORING_NODE_TOKEN is required for per-node HELLO "
            "authentication")
    shared = (shared_token or "").strip()
    if token and shared and hmac.compare_digest(
            token.encode("utf-8"), shared.encode("utf-8")):
        raise SystemExit(
            "WSL_SCORING_NODE_TOKEN must be distinct from LANE_NODE_TOKEN")
    return token


SCORING_NODE_TOKEN = _scoring_node_token(
    os.environ.get("WSL_SCORING_NODE_TOKEN"),
    ALLOW_UNAUTHENTICATED_BENCH,
    LANE_NODE_TOKEN)
HELLO_AUTH_TOKEN = SCORING_NODE_TOKEN or LANE_NODE_TOKEN

# How DIELL ball-detect events flow into scoring:
#   camera   — DIELL fires BALL_EVENT with pin_mask from detect_current_pins().
#              Auto-scoring. Use ONLY when T-Camera + pin_detect.PIN_SPOTS is
#              calibrated against real frames — otherwise you score bogus
#              synthetic pin masks on real balls.
#   manual   — DIELL fires BALL_EVENT with pin_mask=None. Server records the
#              ball happened but does NOT apply a pin count; desk operator
#              enters pins via POST /api/lane/<N>/score. This is the safe
#              default for Phase 8a cutover until T-Camera lands.
#   disabled — DIELL events logged on the Pi but no message sent to server.
#              For bench-testing without scoring side effects.
SCORING_MODE = os.environ.get("WSL_LANE_SCORING_MODE", "manual").lower()
if SCORING_MODE not in ("camera", "manual", "disabled"):
    log.warning(f"Unknown WSL_LANE_SCORING_MODE={SCORING_MODE!r}; falling back to 'manual'")
    SCORING_MODE = "manual"
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

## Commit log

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2026-05-02 Add server-initiated commands (OPEN/CLOSE/RESET) + desk simulator UI
    - Pi handles new command types with distinct LED patterns
    - Server exposes POST /api/lane/{N}/{open,close,reset}
    - HTML adds 3 buttons that POST these commands
    - OPEN_LANE also resets the LaneScoring state (new bowlers, fresh score)
    - Bridges sync HTTP handler to async websocket via run_coroutine_threadsafe
    [lane_node.py]
2026-05-04 Fix Button polarity for AL-ZARD opto-input (PNP active-HIGH output)
    AL-ZARD DST-1R8P-P asserts HIGH when its 24V input fires, opposite of a
    typical pushbutton. Empirically confirmed 2026-05-03 on bench rig with
    18V Ryobi battery to AL-ZARD input 1 -> output O1 -> Pi GPIO 17.
    [lane_node.py]
2026-05-06 Production-safety: SIGTERM handler, try/finally on pulse(), systemd cleanup
    Bench-validated 2026-05-03 that BCM2711 retains GPIO state when lgpio
    releases the line on process death. Both SIGTERM and SIGKILL leave a
    relay stuck closed if it was driving HIGH, which in production = pinsetter
    cycling forever. Three layered mitigations:
    - SIGTERM handler in lane_node.py main(): cancels main task, runs finally
    cleanup that drives PINSETTER_CYCLE LOW and releases gpiozero devices.
    Covers systemd service stops.
    - pulse() wrapped in try/finally: relay always drops open even if a
    CancelledError raised mid-pulse (e.g. WebSocket dropped during
    await asyncio.sleep). Covers network-drop-during-pu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
    [lane_node.py, relay_cleanup.py]
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2026-05-06 Refactor lane_node for pair (lanes 21+22) via per-lane GPIO map
    Each Pi node controls a PAIR of lanes per the Phase 8 architecture
    (one pair per Pi, ~$190-330 BoM, 16 nodes for the full house). The
    prototype was hardcoded to lane 22 only. This refactor:
    - Replaces LANE_ID with LANES = [21, 22] and a LANE_GPIO dict mapping
    each lane to its 4 GPIO assignments (foul / ball2 / cycle / power)
    - Instantiates gpiozero devices per-lane in dicts keyed by lane id
    - Per-lane foul callback via closure-capture (make_foul_callback)
    - pulse() takes a lane_id and drives the right relay
    - command_handler routes by msg.lane to the lane-specific GPIO,
    warns on unknown-lane commands
    - _cleanup_gpio iterate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
    [lane_node.py, relay_cleanup.py]
2026-05-06 Add pin recognition pipeline skeleton (pin_detect.py)
    The OpenCV pipeline that replaces QubicaAMF T-VISION pin counting.
    Reads frames from a USB video capture dongle (T-Camera composite
    NTSC), deinterlaces, classifies each of the 10 pin spots as
    standing/down via grayscale-brightness threshold, returns a 10-bit
    mask matching what wsl_scoring_engine.LaneScoring.record_ball
    consumes.
    Status:
    - detect_pins(): implemented + self-tests pass against synthetic
    frames (7 cases: strike, gutter, head-pin-only, 3-pin-down,
    7-10 split, all-down, single-pin)
    - capture_frame(): stubbed — needs real USB capture device on bench
    - deinterlace(): naive field-drop, sufficient for a starting point
    - crop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
    [pin_detect.py]
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2026-05-06 Add WebSocket protocol versioning to detect schema mismatches
    Both lane_node.py and lane_node_server.py now carry a PROTOCOL_VERSION
    constant. HELLO messages include protocol_version=N. On HELLO, the
    server logs a warning if the node's version doesn't match its own,
    but continues to accept the connection — degrading gracefully is
    preferable to refusing (a refused node = silently broken pinsetter).
    v1 = single-lane (HELLO carried `lane`); v2 = current multi-lane
    (HELLO carries `lanes` list). The server's HELLO handler accepts
    both shapes for backward compat — `lanes` if present, falls back to
    `[lane]` if v1, empty list if neither.
    The PROTOCOL_VERSION bump is the trigger for the warning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
    [lane_node.py]
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2026-05-14 Add programmatic placement script + placed board (post-KiCad-crash recovery)
    KiCad crashed mid-DRC and lost ~45 min of manual placement work. Script
    uses pcbnew Python API to place all 41 components at fixed coordinates
    on a 100x100mm board: terminals around perimeter (J8-J11 top, J4-J7
    bottom, J1-J3 left), watchdog cluster center-left interior, 4 AC
    interposer channels stacked vertically on right interior. Edge.Cuts
    board outline drawn programmatically too. Idempotent — safe to re-run
    if placement needs adjustment.
    [wsl-phase8a.kicad_pcb]
2026-05-14 Optimize placement v2 — AC channels aligned with their terminals
    Each AC channel is now a clean vertical column at the same x as its
    DC_OUT and AC_IN terminals: ch1 at x=20, ch2 at x=40, ch3 at x=60,
    ch4 at x=80. D (rectifier) at y=18 just below the DC_OUT terminal,
    C (smoothing cap) at y=30, R (bleeder) at y=42. The 50mm vertical run
    from R down to AC_IN at y=92 is a single straight trace per channel.
    Watchdog cluster moved into the x-gaps between channel columns
    (x≈10, 28, 48, 70) so channel return traces pass between watchdog
    parts without collision. NE555 at x=32 between ch1/ch2 cols, MOSFETs
    at x=52 between ch2/ch3, LEDs at x=76 between ch3/ch4.
    Cuts the worst trace lengths from ~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
    [wsl-phase8a.kicad_pcb]
2026-05-14 Apply Codex rev A audit fixes: D_PROT, 63V caps, mounting holes
    Three pre-route critical fixes from external review:
    1. AC interposer caps C4-C7: 10uF/50V -> 10uF/63V.
    Field signal can hit ~32V RMS = ~45V peak before transients; 50V
    was operating at the edge. 63V gives proper headroom.
    2. Reverse-polarity protection on +5V input.
    New D_PROT (SS14 Schottky, SMA) between J1 raw input and the rest
    of VCC_5V. Series diode opens if +5V/GND are swapped at install.
    ~0.3V forward drop means downstream rail is 4.7V — within AEDIKO
    and NE555 operating range. SKiDL assigns refdes D9 (after the 8
    existing diode-prefix parts).
    3. M3 mounting holes at 4 corners.
    3.2mm NPTH at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
    [wsl-phase8a.kicad_pcb]
2026-05-14 Add test pads + silkscreen labels (rev A audit pass 2)
    Codex's second-pass review wanted test pads and field-service silkscreen
    labels. Cherry-picked those additions (not Codex's whole script — that
    had two real bugs: J2/J3 vertical overlap and U1/C5 body collision).
    14 test pads added:
    TP1-TP6: VCC_5V, GND, KICK, TIMING_NODE, NE555_OUT, COIL_GND_RETURN
    TP7-TP14: DC_CHx_POS + CHx_RETURN for each of 4 AC channels
    1.5mm round SMD pads on F.Cu with F.Mask aperture (exposed copper for
    probing). Created programmatically as single-pad footprints.
    18 silkscreen labels on F.Silkscreen:
    - Power terminals: +5V/GND, AEDIKO V+/V-, KICK/GND
    - DC OUT (top): CH1-4 DC OUT
    - AC IN (bottom): CH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
    [wsl-phase8a.kicad_pcb]
2026-05-14 Rev A polish per Codex pass 3: tighter timing cluster + shorter labels
    - C1 (timing cap) moved from (12, 65) to (30, 58): directly above
    U1.7/U1.6 (THRES/DISCH). TIMING_NODE trace now ~7mm vs ~20mm prior.
    - C2 (VCC bypass) moved from (28, 55) to (28, 65): hugging U1.8 (VCC)
    and U1.1 (GND), 0.5mm from U1 body left edge.
    - C3 (CTRL filter) moved from (28, 75) to (37, 60): right of U1.5
    (CTRL) for short bypass-to-GND path.
    - R1 (timing pullup) moved from (12, 55) to (32, 52): directly above
    C1, TIMING_NODE pullup loop stays compact.
    - R2 (TRIG pullup) moved from (24, 55) to (25, 67): left of U1.2 (TRIG).
    - D9 (SS14 reverse-polarity) moved from (16, 33) to (15, 22):
    immediately right o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
    [wsl-phase8a.kicad_pcb]
2026-05-14 Fix diode polarity + AC channel pad alignment per Codex pre-route audit
    Codex caught D9 backwards. Verified via .kicad_pcb inspection: at
    rotation 0, KiCad's Diode_SMD:D_SMA puts pin 1 (K) on the LEFT. With
    D9 at (15, 22, 0), K was facing J1 (wrong — that's the raw supply
    side, should be the anode). Trace from J1.1 to D9.A would have had to
    detour around D9's body.
    Three rotation fixes applied:
    1. D9 (SS14) rotation 0 -> 180: anode now on LEFT toward J1.1, cathode
    on RIGHT toward VCC_5V loads. VCC_5V_RAW becomes a straight ~5mm
    horizontal stub from J1 to D9.A.
    2. D1, D2 (diode-OR isolation) rotation 0 -> 180: anodes (pin 2) now
    on LEFT toward U1.7/U1.2 (TIMING_NODE/TRIG, the no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
    [wsl-phase8a.kicad_pcb]
2026-05-14 Add B.Cu keepout zones to force AC channel isolation
    Codex post-route audit caught FreeRouting taking shortcuts: CH1/CH2
    return nets routed on bottom layer (B.Cu) through the watchdog area
    rather than staying in their channel columns. Class-specific keepouts
    require KiCad custom rules (.kicad_dru) DSL which is complex; instead
    applied generic B.Cu keepouts in the 5 gap regions between channel
    columns (x=14-18, 23-37, 43-57, 63-77, 83-92, y=5-95). This blocks
    bottom-layer routing in those gaps, forcing AC returns to stay in
    their channel columns. F.Cu is unaffected so watchdog routes
    (predominantly on top layer) continue normally.
    Two KiCad 10 API quirks discovered while writing this:
    - ZONE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
    [wsl-phase8a.kicad_pcb]
2026-05-14 Fix DRC clearance errors: move C2 and D9 to clear courtyard overlaps
    DRC report from first routed rev surfaced 5 real errors:
    - C2.pad2 (GND) at (28.95, 65.0) was 0.7mm from U1.pad2 (TRIG) at
    (29.525, 65.365), causing shorting + solder-mask-bridge violations.
    C2 moved 4mm left to (24, 65). Pads now 4.6mm apart.
    - D9 at (15, 22) had courtyard overlaps with both J1 (body x=2-14)
    AND channel-1 D3 at (20, 18). Moved DOWN to (10, 35) — in the gap
    between J1 and J2 vertically, at x=10 OUTSIDE the gap_J1_to_ch1
    B.Cu keepout (which starts at x=14). VCC_5V_RAW trace is ~13mm
    diagonal from J1.1 to D9.A, still short.
    - Unconnected NE555_TRIG pin should re-route cleanly after the C2
    move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
    [wsl-phase8a.kicad_pcb]
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2026-05-14 Clean regen with proper TestPoint FPID + delete stale DSN/SES
    Previous .ses import undid the C2 and D9 placement fixes because the
    .ses file contained (place X y z) lines with the old positions. Need
    to do a full DSN → autoroute → SES cycle from the CURRENT placement,
    not import the stale .ses.
    Also fixed test pad FPID: FootprintLoad sets only the footprint name
    without the library prefix ('TestPoint_Pad_1.5x1.5mm'), which still
    doesn't survive DSN export. Added explicit SetFPID with the full
    'TestPoint:TestPoint_Pad_1.5x1.5mm' library:name form.
    Deleted stale .dsn and .ses to force a fresh export on next run.
    [wsl-phase8a.kicad_pcb]
2026-05-14 Move channel test pads to y=48 to clear D9/J2 conflict
    After D9 moved to (10, 35), TP7 at (14, 36) ended up 0mm from D9.pad1
    (VCC_5V) — DRC short error. Same area had TP7 ↔ J2 courtyard overlap.
    Moved all 8 channel test pads (TP7-TP14) from y=36 to y=48. That y
    range is the clean gap between AC bleeders R9-R12 at y=42 and the
    watchdog cluster starting at y=55+. Plenty of clearance to nearby
    components.
    x-positions tweaked from (14, 26, 34, 46, 54, 66, 74, 86) to
    (15, 25, 35, 45, 55, 65, 75, 85) — round numbers, evenly spaced.
    [wsl-phase8a.kicad_pcb]
2026-05-14 Silkscreen polish: consolidate per-pin labels to per-channel
    Was 26 labels with many pairs too close together (KiCad's silk-min-width
    constraint flagged AC1 L1/L2, AC2 L1/L2, etc. for being 4mm apart when
    5mm is the minimum). Title and power-terminal labels were overlapping
    J1/J2/J8 footprint outlines too.
    Cut to 13 labels:
    - Removed individual DC1+ / DC1- / AC1 L1 / AC1 L2 pairs
    - Replaced with single 'CH1 DC' (top) and 'CH1 24VAC' (bottom) labels
    per channel — pin numbers on the terminal outline already show polarity
    - Consolidated power terminal labels: '+5V/GND', 'AEDIKO', 'KICK/GND'
    next to J1, J2, J3 (was 6 separate labels for the 3 terminals)
    - Removed 'WSL Phase 8a Rev A' titl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
    [wsl-phase8a.kicad_pcb]
2026-05-14 Add U1.pin8 -> C2.pin1 VCC track FreeRouting missed
    FreeRouting routed VCC_5V to all pads except U1.pin8, leaving the
    NE555's VCC pin unconnected. Single DRC error, otherwise board is
    clean.
    scripts/fix_u1_vcc.py adds a 3-segment L-shaped track on F.Cu at
    0.5mm width (Power net class):
    U1.pin8 (34.475, 64.095)
    -> UP to (34.475, 62.0) [clears U1 body top at y=63.55]
    -> LEFT to (23.05, 62.0) [horizontal above U1]
    -> DOWN to C2.pin1 (23.05, 65) [tied into existing VCC net]
    Operates on the routed .kicad_pcb directly; does not regen or wipe
    FreeRouting's traces.
    [wsl-phase8a.kicad_pcb]
2026-05-14 Remove bad U1.pin8 VCC tracks; manual interactive route needed
    My fix_u1_vcc.py routed VCC at y=62 which crossed multiple existing
    F.Cu traces (KICK, GND, NE555_CTRL — all run through that y range).
    Added 7 new DRC errors. Programmatic routing without knowing the
    existing trace layout is unsafe; KiCad's push-and-shove interactive
    router handles obstacles correctly.
    undo_u1_vcc_fix.py removes the 3 bad track segments by matching their
    endpoint coordinates exactly. Board back to its state from FreeRouting
    import (1 unconnected error: U1.pin8 VCC).
    Next: manual route in KiCad with X tool.
    [wsl-phase8a.kicad_pcb]
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2026-05-16 Phase 8a code: DIELL ball-detect + manual pin-mask entry
    - lane_node/lane_node.py: bind DIELL photoelectric sensors as
    ball-detect inputs. Per lane, two new Button instances (diell_left,
    diell_right) on GPIO 13/16 (lane 21) and 19/20 (lane 22). Both
    sensors fire one BALL_EVENT per ball via make_ball_detect_callback,
    which dedupes left+right triggers from the same ball with a 200ms
    per-lane lockout.
    DIELL is NPN open-collector with an external 10k pull-up to +12V
    (replacing T-VISION's internal pull-up after Phase 8 retires
    T-VISION). Signal is HIGH at idle, LOW when beam broken — INVERTED
    vs the foul/2nd-ball lamp signals. Bound to `when_released` so the
    falling edge fi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
    [lane_node.py]
2026-05-16 Codex audit fixes: scoring server unification + DIELL safe defaults
    Six findings from the 2026-05-15 Codex audit addressed:
    P0 — Display/scoring server split. wsl_scoring_display.html polled
    relative /api/lane/<N>/scoring, which on the planned :5000 URL hit
    wsl_api.py (no Phase 8 awareness). Pi events land in lane_node_server
    on 8765/8766 instead, so cutover-day display would have been blank.
    Fix: lane_node_server.py now owns the Phase 8 display path:
    - new GET /api/lane/<N>/scoring returning to_scoring_response()
    - new GET /display serving wsl_scoring_display.html from repo root
    The Beelink kiosk URL is now http://192.168.86.36:8766/display?lane=21&mode=league.
    P1 — DIELL synthet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
    [lane_node.py, wsl_scoring_engine.py]
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2026-05-30 Phase 8a: integrate hardware-watchdog kick into daemon
    lane_node.py now pulses the NE555 watchdog on GPIO 12 at ~1Hz via a new
    watchdog_kick_loop(), run via asyncio.gather alongside a connection_manager
    coroutine so the kick is INDEPENDENT of the WS connection — a server outage
    no longer drops the pinsetter; only daemon death / event-loop hang trips the
    watchdog (~11s timeout). _cleanup_gpio() drives the kick low + closes it.
    relay_cleanup.py (systemd ExecStopPost) now also forces GPIO 12 LOW, covering
    the SIGKILL-mid-kick case where a retained-HIGH kick pin would otherwise hold
    the watchdog alive and defeat it.
    Bench-validated on board #2 2026-05-29: D7 solid while the daemon runs alone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
    [lane_node.py, relay_cleanup.py]
2026-06-10 A2 (partial): fix lane-bricking NameError in scoring engine
    _advance_to_next_active ended with `return bowl` (undefined name), raising
    NameError whenever every bowler is game-over -> 500s the scoring call and bricks
    the lane. Changed to a plain `return`. This is the lane-nodes copy of
    wsl_scoring_engine.py; the identical fix + golden-game tests landed in the WSL
    Systems repo (commit a324988). Keep the two copies in sync until the dual-copy is
    collapsed (tracked as an architecture item).
    [wsl_scoring_engine.py]
2026-06-10 A2: foul scores 0 pins, never a strike/spare
    Mirror of the WSL Systems fix. The engine credited the physical pinfall
    on a foul, so a fouled 10-count registered as a strike and a ball-2
    foul that cleared the deck registered as a spare. Now a foul credits 0
    scored pins (Bowl.pins_down = eff = 0) and strike/spare/split detection
    uses eff, not the raw mask; a ball-1 foul respots the rack
    (mask_before_ball=0x3FF) and spare detection is bowls[0].pins_down +
    eff >= 10. Adds tests/test_foul_scoring.py; 300 perfect game still
    passes.
    [wsl_scoring_engine.py]
2026-06-10 A2: resync the live cursor after correcting the in-progress frame
    Mirror of the WSL Systems fix. set_frame_bowls rebuilt a frame's bowls
    but left the live cursor (current_frame_idx / ball_in_frame /
    mask_before_ball) stale, so correcting the IN-PROGRESS frame made the
    next real ball land in the wrong slot. Added _resync_cursor_to_frame,
    invoked only when correcting the current frame; past-frame corrections
    leave the cursor untouched. Adds tests/test_cursor_resync.py.
    [wsl_scoring_engine.py]
2026-06-10 A2: cascade None so the 10th never prints a score skipping an earlier frame
    Mirror of the WSL Systems fix. _recalc_scores continued past an
    unresolved frame (strike/spare awaiting bonus, or an incomplete open
    frame), so a later frame -- notably the 10th -- printed a cumulative
    that silently omitted the unresolved one. A "blocked" flag now cascades
    score=None to every later frame once any frame can't be resolved. Adds
    tests/test_premature_10th.py.
    [wsl_scoring_engine.py]
2026-06-10 P2-P6 + firmware: parallel audit-fix sprint (4 file-owned agents)
    P5 lane server (server/lane_node_server.py, server/state_store.py,
    lane_node/lane_node.py):
    - Shared-token auth, DEFAULT-OFF: LANE_NODE_TOKEN env set on both ends ->
    REST requires X-Lane-Token, WS requires token in HELLO (4401 reject);
    unset = current open behavior + startup warning. wsl_api.py's header
    side already landed in the other repo (d30429d).
    - pickle -> JSON persistence (one-time auto-migration of lane_state.db;
    corrupted blob starts fresh; pickle.load attack surface gone).
    - Locks: clients/metadata mutations + scoring serialization under their
    locks; lane-binding (events only from the node that claimed the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
    [camera.py, config.h, controller_io.py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]
2026-06-10 Sprint 2: lane_node + rp2040_link + camera + systemd/ops (4 file-owned agents)
    lane_node.py (P4 deferred items):
    - WS reconnect no longer leaks orphaned event_sender tasks: each
    connection runs its loops under asyncio.wait(FIRST_COMPLETED) and
    cancels+reaps ALL siblings before reconnecting; event send is
    transactional (failed send re-queues the message, no silent ball loss).
    - Camera-mode per-lane capture-in-flight guard: DIELL retriggers during
    a settle window can't schedule a second capture/phantom BALL_EVENT;
    BALL_DETECT_LOCKOUT_S env-tunable (WSL_LANE_BALL_LOCKOUT_S, default
    0.2 = current; set ~8s at cutover to mirror the 82-70's own masking).
    - _cleanup_gpio is fail-safe-fir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
    [camera.py, controller_cleanup.py, lane_node.py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]
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2026-06-11 Sprint 4: scoring-engine max_possible + 10th-ball-3 display; docs miswire sweep
    wsl_scoring_engine.py (kept byte-identical with the WSL Systems copy;
    a drift-guard test now lives in that repo's suite):
    - _max_possible computes the true maximum from actual frame/ball state
    instead of a flat 12-ball cap (wrong for any game with a non-strike
    frame).
    - set_frame_bowls 10th-frame ball-3 display symbol fixed ('/'/'X'/digit
    derived from ball 2's remainder instead of '6'/literal '10').
    Docs (P8/P9 sweep, all verified against the live firmware/netlist):
    - channel_allocation pin map corrected to GP6-13 fast / GP2 RP_OK /
    GP0-1 UART; hardware cam-stop claim corrected (firmware defers to
    v1.1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
    [phase8_revB_preorder_parts.csv]
2026-06-11 P4: per-lane command dispatch + immediate POWER (default-off, bench-gated)
    command_handler ran all commands in one serial loop, so a 1s CLOSE
    pulse on lane A delayed a POWER_OFF for lane B. Two changes:
    - POWER_ON/POWER_OFF now execute IMMEDIATELY (instant latched relays,
    safety-relevant) and never wait behind any in-flight pulse, in either
    mode. This directly fixes the item's example.
    - Pulse commands (CYCLE/OPEN/CLOSE/RESET) can dispatch to per-lane
    worker queues so lanes run concurrently while a single lane's pulses
    stay strictly ordered (two overlapping pulses on one pinsetter is a
    hazard). Gated by WSL_CONCURRENT_LANE_CMDS, DEFAULT OFF = byte-for-
    byte the original serial b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
    [lane_node.py]
2026-06-11 Ideas #9/#12/#16: trace-replay sim + legality matrix + safety-rail rig
    Three pure-software harnesses over the 82-70 FSM — read-only imports,
    zero edits to cycle_control/io/daemon, all run with plain py -3.
    #9 trace_replay.py: JSON trace format + replay-vs-golden assertion;
    3 FSM-derived golden fixtures (strike / foul / first-ball respot,
    regen via --write, byte-stable). Any FSM edit that changes the output
    sequence breaks replay — the intended CI tripwire. Real bench .jsonl
    captures drop into the same format with no code change.
    #12 test_fsm_legality_matrix.py: declarative 110-cell matrix
    (10 states x 11 events -> IGNORE | ADVANCE(target) | FAULT) pinning
    the FSM's largest unreviewed s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
    [test_fsm_legality_matrix.py, trace_replay.py]
2026-06-11 Ideas #10/#11/#15: flight recorder + shadow soak + cam telemetry
    All observe-only, allocation-bounded, self-swallowing — a recorder or
    telemetry bug can never raise into or slow the control loop; control
    behavior with no env flags set is byte-identical (daemon selftest
    28/28 unchanged).
    #10 flight_recorder.py: 2000-event ring (O(1) append) of output
    changes, state transitions, faults, watchdog kicks; dumps a bounded
    timestamped JSON black box on any fault/trip (atomic tmp+replace,
    retention-capped). Default ON; WSL_FLIGHT_RECORDER=0 kills it.
    #11 ShadowIO (controller_io.py): WSL_CONTROLLER_SHADOW=1 (default
    OFF) runs the FSM on REAL inputs while every output routes to a
    record-only sink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
    [cam_telemetry.py, controller_io.py, flight_recorder.py]
2026-06-11 Idea #14: camera self-check + opt-in empty-reference recalibration
    The slow failure mode of camera scoring is empty-deck reference drift
    (lighting shift, camera bump) degrading every read. Now:
    - frame_health(): exposure/focus sanity over the deck band, surfaced
    for daemon telemetry (default ON, observe-only, never raises).
    - check_empty_reference()/self_check_empty(): at confirmed-empty-deck
    moments, drift-corrected divergence vs the stored reference; FLAGS
    past threshold (WSL_CAM_EMPTY_DIVERGENCE_MAX, default ON).
    - Auto-recalibration default OFF (WSL_CAM_AUTO_RECAL) — even enabled,
    only fires on a high-confidence empty deck under a divergence cap,
    writes atomically with .bak,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
    [camera.py, pin_detect.py]
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
